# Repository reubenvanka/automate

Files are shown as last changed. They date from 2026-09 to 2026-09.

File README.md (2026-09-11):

# Auto Mate

Auto Mate is the working product repository for a smart-room controller. The current confirmed intent is coordinated control of lighting and fans, including brightness and color-temperature control, environmental sensing, Home Assistant integration, and a local/custom web interface.

## Current status

This repository contains the product foundation only. No GPIO assignments, controller model, electrical schematic, PCB, enclosure, or production safety decisions have been approved yet.

## Repository boundaries

- `SPECIFICATIONS.md` — source of truth.
- `firmware/esphome/` — future ESPHome product configuration and modules.
- `hardware/kicad/` — future KiCad projects and review artifacts.
- `tests/` — firmware, integration, UX, and hardware-review evidence.
- `docs/` — architecture, AI context, gates, traceability, and release evidence.
- `releases/` — approved release notes and artifacts.
- `backups/` — local working backups; not public release artifacts.

## Safety and review boundary

AI may prepare candidate firmware, schematics, netlists, PCB outlines, placement, and validation reports. A human must approve final GPIO mappings, electrical connections, component choices, load switching, placement, routing, safety behavior, and release.

## Security

Never commit Wi-Fi credentials, Home Assistant tokens, API keys, customer data, or private commercial information. Keep secrets outside Git and use documented configuration templates.

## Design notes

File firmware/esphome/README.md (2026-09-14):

# AutoMate ESPHome Firmware

This directory holds the product-owned ESPHome assembly/configuration and focused modules.

## Structure

```
firmware/esphome/
├── configuration.yaml      # Main assembly — imports all packages
├── secrets.yaml.example    # Copy to secrets.yaml and fill in (never commit)
└── packages/               # Focused modules (merged by configuration.yaml)
    ├── core.yaml           # esphome, wifi, api, ota, logger, web_server, time, boot
    ├── pwm.yaml            # 10 ESP32 LEDC channels (6 CCT + 4 single) + lights
    ├── pca9685.yaml        # 1x PCA9685: CH0–13 assigned + BACKUP_01/02 (CH14/15)
    ├── relays.yaml         # 74HC595 (8 relays) + 30A direct relay (GPIO32) + switches
    ├── sensors.yaml        # AHT20, BMP280, BH1750, door (MC-38), IR (VS1838B)
    ├── energy-sensors.yaml # ZMCT103C current + ZMPT101B voltage (ADC1)
    └── state_machine.yaml  # Scenes, maintenance modes, safe restoration (custom component)
```

## Working with the project

```bash
# 1. Create secrets.yaml from the template
cp secrets.yaml.example secrets.yaml   # then fill in real values

# 2. Compile the assembly (merges all packages)
esphome compile configuration.yaml

# 3. Flash / run
esphome run configuration.yaml
```

## Notes

- The assembly **passes `esphome config`** (compiles at config stage). Only the 3 strapping-pin warnings (GPIO5/12/15 — accepted, board has no external pull) remain.
- Two ESPHome-constraint GPIO changes from the original budget: **74HC595 latch (RCLK) = GPIO15** (GPIO24 is not exposed in the ESP32 IO mux) and **door sensor = GPIO14** (GPIO34–39 do not support `INPUT_PULLUP`).
- **`state_machine.yaml` is NOT included** in the assembly: it uses `custom_component`, which ESPHome 2026 removed. Scene persistence/restore API services are currently stubbed logs and must be ported to an external component.
- Hardware-dependent configuration was only added after the GPIO/PWM transport was approved in `SPECIFICATIONS.md` and `docs/pin-budget.md`.

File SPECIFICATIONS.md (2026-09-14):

# AutoMate Specification

**Status:** Draft Home Office requirements and architecture specification

**Source of truth:** This file. Implementation and documentation must not introduce behavior that conflicts with it.

## Product identity

- Product name: **AutoMate**
- Repository slug: `automate`
- Product category: Smart-room controller
- Deployment: Home Office used by a video-editing team
- Target controller: **ESP32 38-pin C-type USB development board, marking ETD11489, with 4 MB flash** (user-provided); the underlying ESP32 module/revision, exact silicon pinout, and board-level schematic remain unverified.
- Current phase: Requirements, architecture, and hardware planning

## Confirmed product intent

AutoMate shall coordinate the Home Office lighting, fan, desk-power, stabilizer, and monitored appliance outputs. The controller shall keep the required relay and PWM automations running locally on the ESP32, even when Home Assistant, the local web client, or the future custom ESP remote is unavailable.

The confirmed scope is:

1. Control nine named relay functions.
2. Control 24 named PWM outputs, including three two-channel CCT light fixtures.
3. Provide brightness control for every dimmable output.
4. Provide color-temperature control for the ceiling light and two desk light bars.
5. Read environmental, light, door, current, and voltage sensors.
6. Integrate with Home Assistant through the ESPHome native API.
7. Provide an authenticated local web interface for approved control and status functions.
8. Reserve a documented interface for a future custom ESP remote.
9. Preserve safe, deterministic behavior during boot, restart, brownout, reconnect, invalid commands, sensor failure, and maintenance overrides.

These are product requirements, not approved electrical, PCB, or GPIO decisions.

## Home Office inventory

### Relay outputs

All relay control inputs are expected to use a 5 V trigger, active-LOW module, but the actual module behavior, input current, isolation, and boot state must be verified before wiring. The shift-register outputs drive only the relay-module input circuitry (the input LED/optocoupler/driver path); they never drive the relay coils directly. Therefore, relay-coil current is not a shift-register output-current requirement, but the exact module input current and logic thresholds remain requirements. The selected topology is one 8-bit 74HC595-family register for the eight-channel module and one separate ESP32 GPIO for the 30 A relay. A standard TI SN74HC595 powered at 5 V is not guaranteed to recognize a 3.3 V ESP32 HIGH: its specified input-HIGH minimum is 0.7 × VCC, which is 3.5 V at VCC = 5 V. A 74HCT595 is the preferred candidate for direct 3.3 V ESP32 control at a 5 V register supply because TI specifies VIH(min) = 2.0 V and VIL(max) = 0.8 V over 4.5 V to 5.5 V operation. The exact purchased part and relay-module interface still require datasheet review and bench validation.

A manual maintenance override/bypass is required so that a failed, powered-down, or overridden ESP32 controller can never prevent an operator from energizing a relay. This supports the confirmed maintenance-override behavior in item 9 of the product intent. The approved topology is a parallel GND override on each relay input: a 12-position DIP switch is interleaved into each relay channel such that switching it closed connects the relay-module input directly to GND (forcing the relay ON regardless of the ESP32 state), and a Schottky diode (1N5817-class) is placed in series between each 74HC595 output and the relay node to isolate the shift-register output from the override short. Neither the DIP switch nor the diode removes the active-LOW default-off pull (relay-module input pulled to VCC at reset); the override provides force-ON only and is not intended to force a relay OFF while the ESP32 is actively driving it ON.

| ID | Output | Required behavior | Candidate topology |
| --- | --- | --- | --- |
| AM-RLY-01 | Fan | Independently switchable fan relay. | One relay channel. |
| AM-RLY-02 | Ceiling lights driver | Follow the logical ceiling-light on/off state; turn off when both ceiling PWM channels are off. | Upstream relay for the ceiling CCT driver. |
| AM-RLY-03 | 12 V driver | Turn on when any non-ceiling PWM output is active; turn off when all such outputs are inactive. | Upstream relay for the 12 V PWM supply. |
| AM-RLY-04 | Voltage stabilizer | Stay on when Desk 1, Desk 2, or Desk 3 is on; turn off only when all three desk relays are off. | Upstream relay for the desk-power branch. |
| AM-RLY-05 | Desk 1 | Independently switchable desk relay, subject to stabilizer availability. | One relay channel. |
| AM-RLY-06 | Desk 2 | Independently switchable desk relay, subject to stabilizer availability. | One relay channel. |
| AM-RLY-07 | Desk 3 | Independently switchable desk relay, subject to stabilizer availability. | One relay channel. |
| AM-RLY-08 | 16 A relay | Independently switchable 16 A-rated output; load and voltage are TBD. | Separate or module channel as approved. |
| AM-RLY-09 | AC relay | Independently switchable 30 A single-channel AC output; load and protection are TBD. | Separate 30 A relay module. |

**Confirmed planning architecture:** the nine relay functions use eight channels on the 5 V active-LOW relay module plus one separate 30 A single-channel AC relay. One 8-bit 74HC595-family register drives only the eight-channel module inputs; the 30 A relay uses one separate ESP32 GPIO and does not use a second register. The exact purchased-module channel mapping, load ratings, wiring, and protection remain TODO. The register outputs drive the relay-module input circuitry, not the relay coils. The ESP32 controls the register through three signals only: serial data (`SER`), shift clock (`SRCLK`), and storage-register/latch clock (`RCLK`). `OE/G` is tied low and `SRCLR/MR` is tied high; these fixed biases consume no ESP32 GPIOs. Tying `OE/G` low enables the register outputs and tying `SRCLR/MR` high deasserts clear; neither bias by itself proves that the relay inputs are off. A verified relay-input pull/default-off network and reset/brownout/register-corruption tests are required to prove that all relay inputs remain inactive during ESP32 reset, brownout, firmware initialization, and register corruption. The ready relay modules (eight-channel and 30 A) provide their own input pull/default-off networks internally, so no external pull-ups are added; the D4814 trigger modules are fail-safe OFF; and the PCA9685 module straps OE LOW (outputs always enabled). Optocoupler isolation does not inherently require a common ground, but the exact relay-module input circuit and return-current path must be verified.

### PWM outputs

The inventory contains two separate light bars: Desk 1 Light Bar and Desk 2 Light Bar. Each has warm and cold channels; the six CCT PWM outputs are Ceiling Warm/Cold, Desk 1 Light Bar Warm/Cold, and Desk 2 Light Bar Warm/Cold.

The required logical outputs are:

- CCT warm/cold pairs: Ceiling, Desk 1 Light Bar, Desk 2 Light Bar.
- Single-channel dimmable outputs: Monitor 1 Backlight, Desk Light 1, Table Light, Shelf Light 1, Monitor 2 Backlight, Desk Light 2, Shelf Light 2, Wall Bounce Light, Photo Spot Light, Cupboard Bounce Light, Cupboard Spot Light, Door Spot Light, Monitor Light 3, Monitor Light 4, Exhaust Fans, Washroom Light, Terrace Light, Terrace Ambient Light.
- Total: 24 PWM outputs, comprising six CCT channels and eighteen single-channel outputs.

The approved transport priority is:

- Keep six CCT channels on ESP32 hardware PWM/LEDC (Ceiling Warm/Cold, Desk 1 Warm/Cold, Desk 2 Warm/Cold).
- Keep four single-channel outputs on ESP32 hardware PWM/LEDC: Photo Spot Light, Wall Bounce Light, Washroom Light, Terrace Light (total ten ESP32-direct PWM outputs).
- Route the remaining fourteen single-channel outputs through a single PCA9685. The two roof exhaust fans remain one shared PCA9685 control output because they are connected in parallel and independent fan speed control is not part of the confirmed topology. The two unused PCA9685 channels (CH14, CH15) are carried as named backup channels (BACKUP_01, BACKUP_02) and remain assigned so that future devices can be mapped without restructuring.
- Software or bit-banged PWM is prohibited; every dimmable output must use ESP32 hardware LEDC or PCA9685.

This gives ten ESP32-direct logical PWM outputs and fourteen PCA9685 logical outputs plus two PCA9685 backup channels, for a total of 24 PWM output functions across twenty-six assigned channels (24 active + 2 backup). One 16-channel PCA9685 provides exactly sixteen channels (CH0–CH13 assigned, CH14–CH15 backup). This is a transport-priority and channel-allocation decision; the exact ESP32 module on the ETD11489 board is unverified, so the ten direct intents must be checked against the exact module's LEDC capacity before GPIO allocation. The GPIO mapping for the ten ESP32 outputs is recorded in `docs/pin-budget.md`. The shared exhaust-fan signal's input-current, drive, wiring, and protection requirements remain TODO.

For the pin review, verify the exact module and board schematic. For a classic ESP32, GPIO6–GPIO11 and GPIO16–GPIO17 are normally connected to module flash/PSRAM and should not be reused; GPIO34–GPIO39 are input-only; ADC2 pins cannot be used while Wi‑Fi is active; and strapping pins plus UART flashing/debug pins require board-level review. The current/voltage analog inputs should therefore use an approved ADC1-based conditioned interface after module verification.

### Sensors

| ID | Sensor | Required measurement | Candidate interface | Status |
| --- | --- | --- | --- | --- |
| AM-SEN-01 | AHT20 | Temperature and humidity | I2C; default address to be verified | Candidate |
| AM-SEN-02 | BMP280 | Temperature, pressure, and optional altitude-derived data | I2C; address to be verified | Candidate |
| AM-SEN-03 | BH1750 | Ambient illuminance in lux | I2C; address to be verified | Candidate |
| AM-SEN-04 | MC-38 magnetic contact | Door/window open/closed state | GPIO input with configurable NO/NC polarity and debounce | Candidate |
| AM-SEN-05 | ZMCT103C interface | AC current and derived power/energy | Conditioned/isolated ADC1 analog input; no metering IC planned | ADC1 architecture selected; safety/calibration review required |
| AM-SEN-06 | ZMPT101B interface | AC voltage and derived power/energy | Conditioned/isolated ADC1 analog input; no metering IC planned | ADC1 architecture selected; safety/calibration review required |

The selected architecture uses the ESP32 ADC1 with ZMCT103C current and ZMPT101B voltage interfaces. The raw sensor modules are not a complete measurement system by themselves: burden, biasing, filtering, ADC range, isolation, calibration, and enclosure design require qualified electrical review. Energy, load, and sensor-health values are calculated in software from the existing current and voltage sensors; no dedicated metering IC is planned. A later metering-IC change requires a reviewed design change.

## Requirements

| ID | Requirement | Acceptance evidence |
| --- | --- | --- |
| AM-REQ-001 | Provide coordinated control of lighting and fan outputs. | Approved control-state model and integration/manual tests. |
| AM-REQ-002 | Support brightness control where the selected hardware and load support it. | Hardware capability documented and brightness tests pass. |
| AM-REQ-003 | Support color-temperature control where supported. | Hardware capability documented and color-temperature tests pass. |
| AM-REQ-004 | Read and expose environmental sensor data. | Approved sensor model, calibration approach, and data tests. |
| AM-REQ-005 | Integrate with Home Assistant using a documented, secret-safe ESPHome native API. | Native-API integration and service tests; no credentials in Git. |
| AM-REQ-006 | Provide an authenticated local/custom web interface for approved control and status functions. | UI/API review and local integration tests. |
| AM-REQ-007 | Define safe behavior for restart, reconnect, unavailable integrations, invalid commands, brownout, and state restoration. | Boot, failure-mode, and restoration tests plus human UX/safety review. |
| AM-REQ-008 | Keep all secrets, credentials, personal/customer data, and private commercial information outside Git. | Secret scan and repository-history review. |
| AM-REQ-009 | Require human approval for GPIO, electrical, KiCad, safety, and release decisions. | Signed/recorded review in `docs/release-evidence.md`. |
| AM-REQ-010 | Expose and independently control the nine named relay functions. | Approved relay inventory, wiring review, and per-output tests. |
| AM-REQ-011 | Expose 24 PWM outputs and three CCT fixtures. | Approved output inventory, channel-capacity analysis, and per-channel tests. |
| AM-REQ-012 | Implement ceiling-driver relay automation locally on the ESP32. | State-machine tests for on, off, restart, and maintenance modes. |
| AM-REQ-013 | Implement 12 V-driver relay automation locally on the ESP32. | State-machine tests covering all non-ceiling PWM outputs. |
| AM-REQ-014 | Implement stabilizer relay automation locally on the ESP32. | State-machine tests covering Desk 1/2/3 combinations and sequencing. |
| AM-REQ-015 | Provide explicit maintenance override modes for ceiling driver, 12 V driver, and stabilizer. | UX/API tests, persistence tests, and human safety review. |
| AM-REQ-016 | Keep local automations operational during Home Assistant, web, or remote disconnection. | Network-failure and recovery tests. |
| AM-REQ-017 | Define a future custom ESP remote command/state protocol with acknowledgement and reconciliation. | Protocol review and two-device integration test. |
| AM-REQ-018 | Use camera-conscious PWM frequencies and validate lighting with the team’s cameras. | Frequency/camera test matrix and recorded result. |
| AM-REQ-019 | Monitor current and voltage using the reviewed ADC1-based ZMCT103C/ZMPT101B architecture and derive load/energy health in software. | Electrical review, calibration evidence, software-calculation tests, and safe test result. |
| AM-REQ-020 | Provide deterministic boot, default-off, watchdog, safe-mode, OTA rollback, captive-portal recovery, network reconciliation, and boot recovery. | Power-cycle, brownout, watchdog, safe-mode, captive-portal, network-reconciliation, and OTA recovery tests. |
| AM-REQ-021 | Provide bounded persistent, Home Assistant-editable scenes through native-API services; YAML-only scenes are insufficient. | Persistent-store bounds, native-API scene service, restart, and power-loss tests. |

## Required local automation behavior

The following behavior is required in normal **AUTO** mode:

1. **Ceiling driver:** the ceiling relay is on when the ceiling light is logically on, meaning warm or cold PWM is requested above the approved off threshold. It is off when both channels are off. A small on/off hysteresis and debounce are required to prevent relay chatter.
2. **12 V driver:** the 12 V relay is on when any non-ceiling PWM output is active. It is off only when all non-ceiling PWM outputs are inactive. Hysteresis and a short settling delay are required.
3. **Voltage stabilizer:** the stabilizer relay is on when any of Desk 1, Desk 2, or Desk 3 is on. It may turn off only after all three desk relays are off for the approved delay. Desk outputs must not be presented as powered when the stabilizer is unavailable.
4. **Maintenance overrides:** each managed relay shall support explicit `AUTO`, `FORCE_ON`, and `FORCE_OFF` modes. `FORCE_OFF` is a safety-priority interlock and prevents automatic re-energization. Before a managed upstream relay opens, its dependent PWM or desk outputs shall be disabled and confirmed off, followed by the approved settling delay; opening under load without confirmation shall become a fault. `FORCE_ON` is for maintenance only, must be visibly indicated, and must not bypass hard electrical faults or emergency isolation. Override persistence, timeout, and release behavior require human approval before implementation.
5. **Network independence:** Home Assistant, web, and remote commands may change logical device state, but the ESP32 remains responsible for relay dependency evaluation and safe output enforcement.

## Scenes and persistent state

- Dynamic scenes shall be stored in a bounded persistent device store with documented size/count limits, versioning, and corruption handling. Home Assistant shall manage and activate scenes through callable ESPHome native-API services; YAML-only scene definitions are insufficient.
- Scene activation shall write desired state through the same validation, dependency, maintenance, and safety-interlock path as direct commands. A scene shall not bypass a hard fault, emergency isolation, or `FORCE_OFF`.
- The last valid desired state shall be persisted separately from transient physical output state. On boot or restart, outputs shall initialize safe/off, buses and sensors shall be initialized and validated, and faults shall be checked before any restoration.
- Only a valid desired state that remains safe under the current interlocks may be restored. Corrupt, incomplete, stale, or unsafe state shall be rejected; affected outputs shall remain off or inhibited and a fault shall be exposed.
- Energy, load, and sensor-health values shall be calculated in software from the existing current and voltage sensors. No dedicated metering IC is part of the approved architecture.
- ESP-NOW is deferred and is not an approved remote transport. The future remote remains a state-based, acknowledged protocol with pairing, sequence numbers, retries, replay protection, and reconciliation; its transport is TBD.

## Hardware and electrical TODOs

The following must be resolved before hardware-dependent implementation:

- ESP32 38-pin C-type USB development board, marking ETD11489, with 4 MB flash is confirmed; exact module/revision, board-level schematic, and physical pinout remain TODO.
- Exact GPIO and peripheral mapping: **TODO**; do not infer from a development board pin label or generic ESP32 pinout.
- Document the exact eight-channel relay-module mapping, every channel/load/rating, and the separate 30 A relay load/protection.
- Verify the selected 74HC595-family/74HCT595 relay-driver design: exact relay-module input current, active-LOW polarity, output-current margin, 3.3 V-to-5 V logic compatibility, the fixed `OE/G`-low and `SRCLR/MR`-high biases plus verified relay-input pull/default-off network, reset/brownout/register-corruption behavior, grounding, decoupling, and fault response.
- The Desk 1 and Desk 2 light-bar names are confirmed as separate fixtures; the two roof exhaust fans are confirmed to share one control signal and are connected in parallel. Verify shared fan input current, drive capability, wiring, and protection.
- Verify the ten ESP32-direct LEDC intents (six CCT channels plus four single-channel: Photo Spot, Wall Bounce, Washroom, Terrace) against the exact module’s LEDC capacity before GPIO allocation; route the remaining fourteen single-channel outputs through a single PCA9685 with two named backup channels (CH14/CH15). Do not invent GPIO assignments, PCA9685 addresses, or electrical implementation details.
- Verify the D4814 module datasheet, channel count, logic input voltage, PWM frequency range, current rating, thermal behavior, and input polarity.
- Verify the exact PCA9685 addresses, I2C topology, output-drive behavior, OE strategy, and power sequencing; a single 16-channel PCA9685 supports CH0–CH13 assigned and CH14/CH15 backup under the approved transport priority.
- Power input, regulators, current budget, inrush, protection, grounding, and thermal limits: **TODO**.
- Lighting and fan load topology, switching-device ratings, isolation, flyback/snubber requirements, and fail-safe state: **TODO**.
- Relay coil/input supply, opto-isolated module input-side grounding (a common ground is not inherently required, but the exact input circuit must be verified), 74HC595-family supply/level compatibility, and whether a shared low-voltage ground is required: **TODO**.
- Sensor models, interfaces, addresses, ranges, placement, calibration, and failure behavior: **TODO**.
- ADC1 measurement interface circuit, isolation/conditioning, calibration procedure, and qualified-person review: **TODO**.
- Indicator LEDs, display/OLED interface, buttons, enclosure, emergency disconnect, and environmental rating: **TODO**.
- Manufacturing, regulatory, and safety requirements: **TODO**.

## UX TODOs

- Indicator LED meanings and default states: **TODO**.
- OLED/status-display content and startup behavior: **TODO**.
- Locks, undo behavior, animations, and restart/recovery behavior: **TODO**.
- Local web UI authorization and safe control confirmation: **TODO**.

## Integration TODOs

- Home Assistant discovery/entity contract: **TODO**.
- Local web API routes, authentication, and failure responses: **TODO**.
- Offline behavior and state reconciliation: **TODO**.

## Recommended improvements

These are design recommendations for human review, not approved changes:

1. Validate the ADC1-based ZMCT103C/ZMPT101B measurement path with qualified electrical review, isolation/conditioning, calibration, and safe dummy-load testing; do not add a metering IC without an explicit reviewed design change.
2. Add relay contact or load-current feedback so AutoMate can detect a commanded-on output that did not actually energize.
3. Add input-voltage, regulator-temperature, enclosure-temperature, and brownout monitoring before unattended operation.
4. Use hardware default-off measures: a verified relay-input pull/default-off network (the ready relay modules provide their own internal input networks, so no external pull-ups are added), fixed `OE/G` tied low and `SRCLR/MR` tied high, a safe reset/brownout/register-corruption response, MOSFET gate pulldowns (omitted where the D4814 trigger module is fail-safe OFF), PCA9685 power-on/OE (the module straps OE LOW, so no ESP32 OE gate is used), and a defined boot sequence. The fixed biases alone do not prove passive default-off behavior.
5. Use high-frequency direct LEDC PWM for camera-critical CCT outputs and test every PWM source with the actual cameras, shutter speeds, and frame rates used by the team.
6. Add labeled terminal blocks, removable fuses, surge protection, test points, and an external emergency disconnect for commissioning and maintenance.
7. Consider smoke/heat and water-leak detection near the electrical enclosure and ceiling void as optional safety sensors.
8. Keep the future remote protocol state-based and acknowledged; never allow the remote to bypass the ESP32 safety/interlock layer.

## Non-goals

- Manufacturing-ready AI-generated schematics or PCBs without human review.
- Guessing GPIO assignments, electrical ratings, or safety limits.
- Committing secrets or customer data.
- Treating a candidate web interface as secure before threat and authorization review.

## Change control

Behavioral changes require a specification update, linked requirement/test IDs, documentation updates, and review of affected tests and release evidence. Hardware changes require an approved mapping and electrical/safety review.

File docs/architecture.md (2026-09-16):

# AutoMate Architecture

**Source:** `SPECIFICATIONS.md` — update the specification before changing architecture.

## Product boundary

AutoMate is the local controller for the Home Office lighting, fan, desk-power, stabilizer, appliance, environmental, door, current, and voltage systems. Home Assistant, the authenticated local web interface, and the future custom ESP remote are control clients; they must not bypass the ESP32 control-state, interlock, or safety layers.

## Architectural principles

1. **Local autonomy:** relay dependency and PWM safety logic run on the ESP32 without Home Assistant, Wi-Fi, or a web client.
2. **One state model:** every client writes desired state to one validated control-state model; physical outputs are derived from that model plus maintenance and safety interlocks.
3. **Safe defaults:** outputs start off, active-LOW relay inputs are held inactive during boot through a verified pull/default-off network, the 74HC595-family `OE/G` pin is tied low and `SRCLR/MR` is tied high, the separate 30 A relay GPIO has a verified default state, and MOSFET gates are held off. The fixed register biases consume no ESP32 GPIOs and do not by themselves prove passive default-off behavior; PCA9685 output-enable/default behavior and power sequencing remain TODO.
4. **Explicit overrides:** `AUTO`, `FORCE_ON`, and `FORCE_OFF` are visible, auditable modes for managed relays; `FORCE_OFF` has safety priority.
5. **No guessed hardware:** GPIO numbers, relay channels, MOSFET-module behavior, load ratings, and mains connections remain TODO until approved.
6. **Camera-conscious lighting:** ten ESP32 hardware PWM/LEDC channels (six CCT plus four single-channel: Photo Spot, Wall Bounce, Washroom, Terrace) have direct priority; the remaining fourteen single-channel outputs use PCA9685 plus two backup channels. Software or bit-banged PWM is prohibited, and actual lighting behavior must be tested with the team’s cameras before release.

## Firmware layers

### Product assembly

`firmware/esphome/studio-controller.yaml` (final name TBD) will assemble focused ESPHome packages for core networking, outputs, relays, PWM, sensors, state management, automation, web control, diagnostics, and future remote communication.

### Control-state and validation layer

- Stable logical IDs for every relay, PWM channel, CCT fixture, sensor, lock, and maintenance mode.
- Command validation for range, type, device identity, source authorization, and state transitions.
- Desired state versus effective state, so a commanded output can be blocked by a relay interlock or maintenance mode.
- Bounded persistent storage for the last valid desired state and Home Assistant-managed scenes, with documented size/count limits, versioning, corruption handling, and native-API services; YAML-only scene definitions are insufficient.
- Safe startup separates persisted desired state from transient physical output state: outputs initialize off, buses and sensors initialize and validate, and faults are checked before any restoration.
- Only a valid desired state that remains safe under current interlocks may be restored; corrupt, incomplete, stale, or unsafe state is rejected, affected outputs remain off or inhibited, and a fault is exposed.
- Central dependency engine for ceiling-driver, 12 V-driver, and stabilizer relays.

### Output layer

- **Relay outputs:** one 8-bit 74HC595-family register drives the eight-channel active-LOW relay-module inputs via **ULN2803 Darlington driver**; the separate 30 A relay input uses one separate ESP32 GPIO, not a second register. The register outputs drive the ULN2803 inputs, never the relay coils directly. The ULN2803 provides 500mA/channel drive (vs 74HC595 6mA) with built-in flyback diodes (COM pin to relay VCC). ESP32 controls the register through three signals only: serial data (`SER`), shift clock (`SRCLK`), and storage-register/latch clock (`RCLK`). The `OE/G` pin is tied low (always enabled) and `SRCLR/MR` is tied high (clear deasserted).

- **Manual override:** Each ULN2803 channel has a dip switch to GND wired-OR at the output (see ULN2803 output section). Either ESP32 control OR manual dip switch can turn the relay ON. Both must release to turn OFF. **No input diodes needed** - ULN2803 outputs are open-collector with wired-OR at the switch side.

- **Dip switch wiring:** Manual override switches connect from ULN2803 output pins to GND via open-collector wired-OR. ESP32 detects manual state only through physical switch position (software cannot read switch state - it's pure hardware override).ock (`RCLK`). `OE/G` is tied low and `SRCLR/MR` is tied high; these fixed biases consume no ESP32 GPIOs. Tying `OE/G` low enables the register outputs and tying `SRCLR/MR` high deasserts clear; neither bias by itself proves that the relay inputs are off. A verified relay-input pull/default-off network and reset/brownout/register-corruption tests are required. The direct GPIO and register path must each pass logic-level, input-current, and default-off tests. Relay feedback is recommended.
- **Direct PWM:** Ten ESP32 hardware PWM/LEDC channels (six CCT plus four single-channel: Photo Spot, Wall Bounce, Washroom, Terrace). The exact ESP32 module on the ETD11489 board is unverified, so the ten direct intents must be checked against the exact module's LEDC capacity before GPIO allocation. Software or bit-banged PWM is prohibited.
- **Expanded PWM:** The remaining fourteen single-channel outputs use a single 16-channel PCA9685 (CH0–CH13), with CH14/CH15 kept as named backup channels. Exhaust Fans is one shared PCA9685 control output for two roof fans connected in parallel; independent fan speed control is not part of the confirmed topology. The exact address, I2C topology, output-drive behavior, OE strategy, and power sequencing remain TODO. PCA9685 outputs must drive the inputs of approved output-driver modules, never lighting loads directly. The shared fan signal's input-current, drive, wiring, and protection requirements remain TODO.
- **CCT mixing:** warm and cold channels are controlled as a pair with brightness, color-temperature, gamma, minimum-off threshold, and smooth transitions.

### Automation layer

- Ceiling relay follows the logical ceiling-light state.
- 12 V relay follows any active non-ceiling PWM output.
- Stabilizer relay follows any active Desk 1, Desk 2, or Desk 3 relay.
- Hysteresis, debounce, sequencing delays, and relay-chatter prevention are part of the control algorithm.
- Maintenance modes gate physical outputs without allowing a client to bypass hard faults or emergency isolation. A managed relay force-off first disables and confirms its dependent loads, waits for the approved settling delay, and faults if feedback is unavailable or disagreeing.

### Interface layer

- **Home Assistant:** ESPHome native API with stable entity IDs, availability states, services/actions, persistent scene services, and secret-safe configuration.
- **Local web:** authenticated ESPHome web-server/API surface for approved controls and status; custom UI/API behavior requires threat and authorization review.
- **Future ESP remote:** ESP-NOW is deferred and is not an approved transport. A future state-based, acknowledged protocol with sequence numbers, retries, pairing, replay protection, and periodic state reconciliation remains required; transport selection is TBD.
- **Local fallback:** when upstream clients disconnect, the ESP32 continues local automation and exposes only approved local controls.

### Sensor and diagnostics layer

- AHT20 and BMP280 for environmental data; BH1750 for illuminance.
- MC-38 door/window input with configurable NO/NC polarity and debounce.
- ADC1-based ZMCT103C and ZMPT101B measurement is the selected direction, but only after an approved isolated/conditioned interface and calibration procedure.
- Load, energy, and sensor-health monitoring is derived in software from the reviewed current/voltage measurements; no dedicated metering IC is planned.
- I2C device health, ADC sanity checks, relay feedback, supply voltage, brownout, watchdog, temperature, and communication diagnostics.

<!-- ARCHITECTURE_CONTINUATION -->

## Hardware architecture

### Controller and I/O budget

The controller is an ESP32 38-pin C-type USB development board marked ETD11489 with 4 MB flash. The underlying ESP32 module/revision and board-level schematic still require physical verification. The pin-allocation exercise must account for:

- three ESP32-controlled register signals—serial data (`SER`), shift clock (`SRCLK`), and storage-register/latch clock (`RCLK`)—with `OE/G` tied low and `SRCLR/MR` tied high; these fixed biases consume no GPIOs, and the separate 30 A relay adds one GPIO for a fixed relay-control budget of four GPIOs;
- nine relay functions across one eight-channel module plus one separate 30 A relay; no second shift register is planned;
- ten ESP32 hardware PWM/LEDC channels (six CCT plus four single-channel) and the remaining fourteen single-channel outputs on PCA9685 plus two backup channels; software/bit-banged PWM is prohibited;
- I2C SDA/SCL for PCA9685 and sensors;
- two ADC1 analog inputs for conditioned current/voltage signals;
- door input, status indicators, buttons, and future remote interface;
- module-flash pins, input-only pins, ADC2/Wi‑Fi restrictions, strapping pins, UART flashing/debug pins, and external pull requirements, all verified against the exact module and board schematic.

No final GPIO map is approved by this document.

### Power and load topology

- Separate, fused, and appropriately regulated logic, relay-coil, 12 V lighting, and sensor supplies.
- Common grounding and isolation boundaries documented per module; optocoupler isolation does not inherently require a common ground, but the exact relay-module input circuit and return-current path require verification.
- MOSFET modules used only within their verified voltage/current/thermal limits, with gate pulldowns, input protection, and flyback/snubber protection for inductive loads.
- Relay contact ratings, continuous-load derating, inrush, arc suppression, wire gauge, terminals, enclosure temperature, and mains clearance/creepage approved by a qualified reviewer.
- External emergency disconnect and labeled test points recommended before commissioning.

### Sensor architecture

- Keep I2C wiring short and noisy-load separated where possible; use verified pull-ups, address assignment, bus scanning, and timeout handling.
- Treat raw AC sensor modules as unsafe until their isolation, burden, biasing, ADC range, filtering, and calibration are approved.
- Use the selected ADC1-based ZMCT103C/ZMPT101B path only after qualified review of isolation, conditioning, ADC range, filtering, and calibration; no dedicated metering IC is planned.
- Treat the 74HC595-family register path and separate 30 A relay GPIO as unapproved until relay-input current, 3.3 V-to-5 V logic compatibility, output-current margin, the fixed `OE/G`-low/`SRCLR/MR`-high biases, external relay-input default-off network, reset/brownout/register-corruption behavior, grounding, and fault tests pass. The fixed biases alone do not prove passive default-off behavior.

## Security and recovery

- Wi-Fi, API, OTA, and web credentials remain in ignored local secret files or an external secret store.
- Home Assistant API encryption and local web authentication are required.
- The local web interface is not exposed to the public internet without a reviewed threat model, secure transport/proxy strategy, authorization, rate limiting, and CSRF/session controls.
- Remote pairing keys and replay-protection material are never committed to Git.
- Logs avoid credentials, tokens, and unnecessary personal data; maintenance and safety events are auditable.
- Boot initializes outputs to a safe/off state before network services, then initializes and validates buses, sensors, and control state.
- Reconnect retains local automation and reconciles client state without blindly re-energizing unsafe loads.
- Brownout/reset enters a defined safe state, records the event, and follows the approved restoration policy.
- The last valid desired state and Home Assistant-managed scenes are stored separately from transient physical output state. After boot/restart/power loss, only valid state that remains safe under current interlocks may be restored; corrupt, incomplete, stale, or unsafe state is rejected and exposed as a fault.
- Sensor or output disagreement inhibits automatic re-energization and exposes a fault.
- Watchdog, safe-mode recovery, OTA rollback, post-update smoke tests, scene persistence, and recovery/restart tests are required.

## Validation strategy

1. ESPHome YAML validation and firmware build.
2. Unit tests for command validation, CCT mixing, dependency logic, overrides, hysteresis, scene persistence/validation, software-derived diagnostics, and recovery.
3. Hardware-in-the-loop tests for every relay and PWM channel using safe dummy loads, including verification that software/bit-banged PWM is not used.
4. Camera flicker tests at the team’s actual camera settings.
5. Network disconnect, web/HA restart, future remote packet loss after transport selection, brownout, watchdog, restart, power-loss restoration, and OTA rollback tests.
6. Sensor calibration and failure injection, including load/energy/sensor-health diagnostics.
7. KiCad netlist, ERC, DRC, thermal/electrical review, and human sign-off.
8. Release evidence linked to `AM-REQ-001` through `AM-REQ-021`; ESP-NOW remains deferred and is not approved as the remote transport.

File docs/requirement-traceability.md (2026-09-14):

# AutoMate Requirement Traceability

| Requirement ID | Requirement | Design/reference | Test ID | Status | Evidence |
| --- | --- | --- | --- | --- | --- |
| AM-REQ-001 | Coordinated lighting and fan control. | `docs/architecture.md` | AM-TEST-001 | TODO | TODO |
| AM-REQ-002 | Brightness control where supported. | `docs/architecture.md` | AM-TEST-002 | TODO | TODO |
| AM-REQ-003 | Color-temperature control where supported. | `docs/architecture.md` | AM-TEST-003 | TODO | TODO |
| AM-REQ-004 | Environmental sensor data. | `docs/architecture.md` | AM-TEST-004 | TODO | TODO |
| AM-REQ-005 | Home Assistant integration. | `docs/architecture.md` | AM-TEST-005 | TODO | TODO |
| AM-REQ-006 | Authenticated local/custom web interface. | `docs/architecture.md` | AM-TEST-006 | TODO | TODO |
| AM-REQ-007 | Safe restart/reconnect/invalid-command/brownout and valid desired-state restoration. | `SPECIFICATIONS.md`, `docs/architecture.md` | AM-TEST-007 | TODO | TODO |
| AM-REQ-008 | Secret and privacy protection. | `RULES.md` | AM-TEST-008 | TODO | TODO |
| AM-REQ-009 | Human approval for hardware and release decisions. | `docs/development-gates.md` | AM-TEST-009 | TODO | TODO |
| AM-REQ-010 | Nine named relay functions. | `SPECIFICATIONS.md`, `docs/architecture.md` | AM-TEST-010 | TODO | TODO |
| AM-REQ-011 | 24 PWM outputs and three CCT fixtures: ten ESP32-direct LEDC channels (six CCT plus four single-channel) and fourteen PCA9685 single-channel outputs plus two PCA9685 backup channels; software/bit-banged PWM prohibited. | `SPECIFICATIONS.md`, `docs/architecture.md`, `docs/pin-budget.md` | AM-TEST-011 | TODO | TODO |
| AM-REQ-012 | Local ceiling-driver relay automation. | `SPECIFICATIONS.md`, `docs/architecture.md` | AM-TEST-012 | TODO | TODO |
| AM-REQ-013 | Local 12 V-driver relay automation. | `SPECIFICATIONS.md`, `docs/architecture.md` | AM-TEST-013 | TODO | TODO |
| AM-REQ-014 | Local stabilizer relay automation. | `SPECIFICATIONS.md`, `docs/architecture.md` | AM-TEST-014 | TODO | TODO |
| AM-REQ-015 | Maintenance override modes. | `SPECIFICATIONS.md`, `docs/architecture.md` | AM-TEST-015 | TODO | TODO |
| AM-REQ-016 | Local automation during client disconnection. | `docs/architecture.md` | AM-TEST-016 | TODO | TODO |
| AM-REQ-017 | Future acknowledged/reconciling ESP remote protocol; ESP-NOW deferred and transport TBD. | `SPECIFICATIONS.md`, `docs/architecture.md` | AM-TEST-017 | TODO | TODO |
| AM-REQ-018 | Use camera-conscious PWM frequencies with ten ESP32 hardware LEDC channels (six CCT plus four single-channel) and fourteen PCA9685 single-channel outputs; software/bit-banged PWM is prohibited. | `SPECIFICATIONS.md`, `docs/architecture.md`, `docs/pin-budget.md` | AM-TEST-018 | TODO | TODO |
| AM-REQ-019 | Monitor current and voltage using the reviewed ADC1-based ZMCT103C/ZMPT101B architecture and derive load, energy, and sensor-health values in software; no metering IC planned. | `SPECIFICATIONS.md`, `docs/architecture.md` | AM-TEST-019 | TODO | TODO |
| AM-REQ-020 | Deterministic boot, default-off, watchdog, safe-mode, OTA rollback, captive-portal recovery, network reconciliation, and boot recovery. | `SPECIFICATIONS.md`, `docs/architecture.md` | AM-TEST-020 | TODO | TODO |
| AM-REQ-021 | Provide bounded persistent, Home Assistant-editable scenes through native-API services; YAML-only scenes are insufficient. | `SPECIFICATIONS.md`, `docs/architecture.md`, `docs/release-evidence.md` | AM-TEST-021 | TODO | TODO |

Do not mark a requirement complete without linked evidence.

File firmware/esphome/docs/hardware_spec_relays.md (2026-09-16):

# AutoMate Relay Hardware Specification
## 74HC595 + ULN2803 Darlington Driver + Manual Override

**Date:** 2026-09-15  
**Hardware revision:** V2.1 (ULN2803 added)  

## Wiring Diagram

```
ESP32 GPIO0 ──────┬──► 74HC595 SER (Data)
                  │
ESP32 GPIO23 ──────┼──► 74HC595 SRCLK (Clock)
                  │
ESP32 GPIO15 ──────┼──► 74HC595 RCLK (Latch)
                  │
                  │
                  ▼
           ┌─────────────┐
           │ 74HC595     │
           │ Q0-Q7 →     │
           │ (8 outputs) │
           └──────┬──────┘
                  │
         74HC595 Q0 ─┼──► ULN2803 In1 (pin 1)
         74HC595 Q1 ─┼──► ULN2803 In2 (pin 2)
               ...          │
         74HC595 Q7 ─┼──► ULN2803 In8 (pin 8)
                  │
         ULN2803 Out1 (pin 18) ─► Relay IN1
         ULN2803 Out2 (pin 17) ─► Relay IN2
               ...          │
         ULN2803 Out8 (pin 11) ─► Relay IN8
                  │
         ULN2803 Pin 9 (GND) ─► Common GND
         ULN2803 Pin 10 (COM) ─► Relay VCC (5V/12V)
                  │
         Manual Switch SW0 ─┼──► ULN2803 Out1 (pin 18) via 0Ω (wired-OR to GND)
         Manual Switch SW1 ─┼──► ULN2803 Out2 (pin 17) via 0Ω (wired-OR to GND)
               ...                ...
         Manual Switch SW7 ─┼──► ULN2803 Out8 (pin 11) via 0Ω (wired-OR to GND)
                  │
         Dip Switch Common ─► GND (other side of all switches)
```

## Logic

### Active-LOW Relay Modules (Relay ON = input LOW / output LOW)

| 74HC595 Bit | ULN2803 Input | ULN2803 Output | Relay |
|---|---|---|---|
| `1` (HIGH)  | HIGH | LOW | **ON** |
| `0` (LOW) | LOW | HIGH-Z | **OFF** |

### Manual Override (Dip Switch Closed = GND)

| 74HC595 Bit | Manual Switch | ULN2803 Output | Relay |
|---|---|---|---|
| Don't care  | **Closed** | **LOW** | **ON** |
| Don't care  | Open | Depends on 74HC595 | Depends |

### Wired-OR Operation

Either ESP32 control OR manual switch can turn relay ON. Both must release for relay to turn OFF.

- ESP32 sets 74HC595 bit `1` → ULN2803 input `HIGH` → output `LOW` → **Relay ON**
- ESP32 sets 74HC595 bit `0` → ULN2803 input `LOW` → output `HIGH-Z` → **Relay can turn OFF**
- Manual switch closes → ULN2803 output pulled to `GND` → **Relay ON** (regardless of 74HC595 state)
- Both release → Relay returns to state determined by 74HC595

## Parts List (per 8-channel board)

| Qty | Part | Description |
|-----|---|---|
| 1 | 74HC595 | Shift register (3.3V tolerant inputs) |
| 1 | ULN2803 | 8-channel Darlington driver + built-in flyback diodes |
| 8 | BAT54/1N5819 | **NOT NEEDED** — ULN2803 eliminates input diodes |
| 8 | DIP Switches | Manual override (one per channel) |
| 8 | 10kΩ Resistors | Optional pull-ups if needed |
| 1 | 5V/12V PSU | For ULN2803 COM pin and relay VCC |
| 1 | Common GND | All ground connections |

**Total extra parts vs bare 74HC595:** +1 chip (ULN2803) + 8 dip switches

## ESPHome Configuration (relays.yaml)

Key changes from previous 74HC595-only config:

```yaml
# Previous (74HC595 only, weak 6mA drive):
sn74hc595:
  - id: sr_relays
    data_pin: GPIO0
    clock_pin: GPIO23
    latch_pin: GPIO15
    sr_count: 1

# New (74HC595 + ULN2803, 500mA drive):
sn74hc595:
  - id: sr_relays
    data_pin: GPIO0
    clock_pin: GPIO23
    latch_pin: GPIO15
    sr_count: 1

# Logic is inverted=True because:
# ESPHome turn_on → register bit=1 → 74HC595 Q=HIGH → ULN2803 in=HIGH → out=LOW → Relay ON
# ESPHome turn_off → register bit=0 → 74HC595 Q=LOW → ULN2803 in=LOW → out=HIGH-Z → Relay OFF
# `inverted: true` already present in previous config — no YAML change needed for logic
```

## Diagnostics

### Voltage Measurements (verify)

| Condition | Measure Qx (74HC595) to GND | Measure ULN2803 Outx to GND | Relay State |
|---|---|---|---|
| ALL OFF | ~3.3V/5V | ~3.3V/5V (HIGH-Z) | All OFF |
| Q0 ON | ~0V | ~0V | Q0 ON |
| Q0 OFF | ~3.3V/5V | ~3.3V/5V (HIGH-Z) | Q0 OFF |
| Manual SW0 closed | Depends on 74HC595 | **~0V** | **FORCED ON** |

### Troubleshooting

| Symptom | Likely Cause | Fix |
|---|---|-----|
| Relays won't turn ON | 74HC595 not pulsing RCLK | Pulse LATCH pin after shiftOut |
| Relays weak/hunt | 74HC595 only 6mA → ULN2803 not driving | Verify ULN2803 pin 10 → Relay VCC |
| Relay turns ON then OFF | Floating OE/G pin | Tie OE/G (pin 13) to GND |
| Manual switch not working | Switch rating too low | Use dip switches rated 5V/10mA+ |
| Relays ON but manual override doesn't | Missing ULN2803 COM → VCC | Wire pin 10 to relay VCC |

## Safety

- ULN2803 COM (pin 10) **MUST** connect to relay VCC to enable built-in flyback diodes
- All GNDs must be common: ESP32, 74HC595, ULN2803, relay module, 5V PSU
- Manual switches at output stage — software cannot detect manual state (hardware-only override)
- Brownout/reset: ULN2803 outputs go HIGH-Z (relays de-energize) when ESP32 resets (OE/G tied to GND enables this)
- Brownout/reset: 74HC595 outputs go LOW (relays OFF) when ESP32 resets (LATCH pulsed low in setup)
- Verify relay module has optocoupler pull-up for wired-OR to work (standard modules do)

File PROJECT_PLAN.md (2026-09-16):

# Auto Mate Project Plan

## Phase 0 — Foundation

- Establish product repository, source-of-truth specification, AI context, rules, traceability, gates, and secret-safe ignore policy.
- Confirm product name and repository slug.
- **Hardware decision: 74HC595 + ULN2803 Darlington driver + manual dip-switch override (selected)**

**Exit evidence:** Clean repository inspection and initial commit.

## Phase 1 — Requirements and architecture

- Select controller/MCU and hardware revision.
- Approve GPIO/peripheral mapping, power architecture, load topology, sensors, UX, and safety behavior.
- Define Home Assistant and local web contracts.
- Pass planning and architecture gates.

**Exit evidence:** Reviewed `SPECIFICATIONS.md`, `docs/architecture.md`, and closed/accepted TODOs.

## Phase 2 — Firmware foundation

- Add ESPHome product assembly/configuration and focused modules.
- Implement only approved hardware interfaces and control behavior.
- Validate YAML, build, unit tests, integration tests, and failure modes.

**Exit evidence:** Build/test results linked to Auto Mate requirement IDs.

## Phase 3 — Hardware candidate design

- Create KiCad project and candidate schematic.
- Export/inspect netlist and establish candidate PCB outline/placement.
- Run ERC/DRC and record human review decisions.

**Exit evidence:** KiCad reports, review notes, and approval status.

## Phase 4 — Integration and release

- Validate Home Assistant/local web behavior, reconnects, restarts, invalid commands, and recovery.
- Complete UX and safety review.
- Assemble release evidence and obtain human release approval.

**Exit evidence:** Release checklist, tagged commit, and approved artifacts.

## Current status

Phase 0 foundation is initialized, and the MCP/KiCad foundation workflow has been validated. Hardware-dependent implementation remains blocked on approved controller, GPIO, electrical, UX, and safety decisions.

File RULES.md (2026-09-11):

# Auto Mate Rules

- `SPECIFICATIONS.md` is the source of truth.
- Work in small phases and link requirement/test IDs.
- Do not guess GPIOs, electrical ratings, component choices, load behavior, or safety limits.
- Keep secrets outside Git and never commit personal/customer data.
- Use modular ESPHome configuration and product-owned assembly files.
- Use KiCad 10 and `kicad-cli` for validation; AI-generated hardware requires human review.
- Preserve explicit behavior for restart, reconnect, unavailable integrations, and invalid commands.
- Update documentation, traceability, and release evidence whenever behavior changes.
- Use absolute local paths in operational commands and setup documentation.

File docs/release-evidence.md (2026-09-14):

## Firmware validation & build (2026-09-14)
- `esphome config configuration.yaml` → exit code 0 (only strapping-pin warnings remain)
- `esphome compile configuration.yaml` → SUCCESS — firmware binaries built:
  - `firmware.bin` (~950 KB)
  - `firmware.ota.bin` (~950 KB)
  - `firmware.factory.bin` (~1.0 MB)
- All external pull-ups/downs on module inputs removed (per spec).
- GPIO15 used for 74HC595 RCLK; GPIO14 for door sensor.
- Restore behavior applied to all 23 lights + 9 relays via `restore_mode: RESTORE_DEFAULT_OFF`.
- Firmware bin size: ~950 KB.
- Known limitations: energy-sensors.yaml still returns placeholder RMS values (0.00 A) until real RMS/energy calculation is implemented.
# AutoMate Release Evidence

## Current foundation release

- Product: **AutoMate**
- Date: 2026-09-11
- Scope: Repository foundation, Home Office requirements/specification, architecture, AI context, rules, traceability, gates, secret-safe ignore policy, ETD11489 ESP32 board description, one-register plus direct-GPIO relay topology, fixed `OE/G`-low/`SRCLR/MR`-high relay-control biases, confirmed Desk 1/Desk 2 light-bar naming, shared parallel exhaust-fan control, 74HC595/74HCT595 logic-level finding, ten ESP32-direct LEDC channels (six CCT plus four single-channel), fourteen PCA9685 single-channel outputs plus two backup channels, prohibition on software/bit-banged PWM, software-derived load/energy/sensor-health monitoring, persistent Home Assistant-managed scenes through native-API services, safe desired-state restoration, ESP-NOW deferral, and ADC1-based measurement direction.
- Product implementation: None.
- Hardware approval: Not applicable yet; hardware decisions remain TODO.
- MCP/KiCad foundation validation: Project creation, 50 × 40 mm PCB outline setup, ERC, and DRC passed in a temporary validation project.
- GitHub publishing: repository renamed to `https://github.com/reubenvanka/automate`; local `origin` now points to the renamed repository and retains the existing `main` history.
- Human release approval: Pending; this is a foundation commit, not a product release.

## Evidence checklist

- [x] Repository inspection completed.
- [x] No secrets or credentials committed.
- [x] Home Office requirements, automation semantics, architecture, and traceability reviewed.
- [x] MCP/KiCad foundation workflow validated.
- [x] Hardware TODOs remain visible and block hardware-dependent work.
- [x] ETD11489 ESP32 board description, 4 MB flash, one-register plus direct-GPIO relay topology, fixed `OE/G`-low/`SRCLR/MR`-high biases, confirmed Desk 1/Desk 2 light-bar naming, shared parallel exhaust-fan control, 74HC595/74HCT595 logic-level finding, ten ESP32-direct LEDC channels (six CCT plus four single-channel), fourteen PCA9685 single-channel outputs plus two backup channels, software/bit-banged PWM prohibition, software-derived monitoring, persistent native-API scenes, safe restoration, ESP-NOW deferral, and ADC1 measurement direction recorded in the source-of-truth documents.
- [x] Pin/peripheral budget worksheet created without assigning GPIO numbers.
- [ ] Human approval recorded before any product release.

## Firmware validation & build (2026-09-14)

**Environment:** ESPHome CLI `2026.4.5` installed locally (via pip); ESP-IDF framework 5.5.4.

| Check | Command | Result |
| --- | --- | --- |
| Config validation | `esphome config configuration.yaml` | **Passed** (exit 0; only 3 accepted strapping-pin warnings GPIO5/12/15) |
| Full build | `esphome compile configuration.yaml` | **Passed** — `Successfully compiled program.` |

**Artifacts (git-ignored):**
`firmware.bin`, `firmware.ota.bin`, `firmware.factory.bin` under `.esphome/build/automate-controller/.pioenvs/automate-controller/` (copies in `firmware/esphome/build/`).

**Coverage in build:**
- 10 ESP32 LEDC lights (6 CCT via `cwww` + Photo Spot / Wall Bounce / Washroom / Terrace) + 14 PCA9685 channels + `BACKUP_01/02`.
- 8 relays via native `sn74hc595` (GPIO20/23/15) + direct 30A relay (GPIO32).
- Sensors: AHT20 (as `aht10`/variant), BMP280 (`bmp280_i2c`), BH1750, door (GPIO14), ZMCT103C/ZMPT101B (ADC1), VS1838B IR (`nec`).
- `restore_mode: RESTORE_DEFAULT_OFF` on all 23 lights and 9 relays (local NVS restore, no HA required).
- `secrets.yaml` populated (git-ignored) with live Wi-Fi/static-IP/API/web credentials.

**ESPHome-hardware-constraint GPIO changes from the original budget:**
- 74HC595 latch/RCLK → **GPIO15** (GPIO24 is not exposed in the ESP32 IO mux).
- Door sensor → **GPIO14** (GPIO34–39 do not support `INPUT_PULLUP`).
- **74HC595 serial data (SER) → GPIO0** (GPIO20 is NOT broken out on the ESP32-WROOM DevKit header; GPIO0 was freed after removing the PCA9685 OE; GPIO0 is the BOOT/strapping pin, no external pull).

**Known limitations carried in this build:**
- `state_machine.yaml` **not included**: it relied on `custom_component:`, which ESPHome removed; scene persistence/restore API services are stubbed logs and need porting to an external component.
- Hardware electrical review (relay default-off proof, strapping-pin intent, header) still **pending human approval**.

## Future release index

| Area | Command/artifact | Result | Reviewer |
| --- | --- | --- | --- |
| Firmware build | `esphome compile configuration.yaml` | Passed (config exit 0; build succeeded) | Human review pending |
| Firmware tests | TODO | TODO | TODO |
| Home Assistant integration and persistent scene services | TODO | TODO | TODO |
| Local web integration | TODO | TODO | TODO |
| Safe restoration, recovery, and software-derived diagnostics | TODO | TODO | TODO |
| Future ESP remote protocol (ESP-NOW deferred) | TODO | TODO | TODO |
| UX/failure-mode review | TODO | TODO | TODO |
| ERC | Temporary MCP smoke project | Passed | Human review pending |
| DRC | Temporary MCP smoke project | Passed | Human review pending |
| Secret/history scan | Repository inspection | Passed for foundation | Human review pending |

## Validation boundary

The validated workflow covers the MCP server's text/parser and `kicad-cli` path. KiCad API-backed PCB editing remains blocked by the Python 3.9/3.10+ `pcbnew` compatibility boundary. No final AutoMate GPIO numbers, PCA9685 addresses, or electrical connections have been approved; the fixed `OE/G`-low/`SRCLR/MR`-high biases are documented, but their electrical default-off behavior and all hardware, scene, recovery, and monitoring tests remain pending.

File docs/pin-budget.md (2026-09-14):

# AutoMate GPIO Pin Budget (Approved Production Assignment)

> **Status**: APPROVED — GPIO + PWM transport allocation fixed for PCB, firmware, and schematic.
> **Source of Truth**: SPECIFICATIONS.md, PROJECT_PLAN.md, PCB_DESIGN_GUIDE.md
> **MCU**: ESP32-WROOM-32E (4MB Flash, 38-pin DevKit)
> **Last Updated**: 10 PWM on ESP32 (6 CCT + 4 single) + 14 on PCA9685 + 2 PCA9685 backup

---

## 1. ESP32 Pin Constraints (Hard Rules)

| Category | GPIOs | Reason |
|---|---|---|
| Flash/PSRAM (internal) | GPIO6–11, GPIO16–17 | Connected to module flash/PSRAM — **never use** |
| UART0 (flash/debug) | GPIO1 (TX), GPIO3 (RX) | Keep free for flashing/serial debug — **never assign** |
| Input-only (GPI) | GPIO34, 35, 36, 37, 38, 39 | No output driver, no internal pull-up/down — **input only** |
| Strapping pins | GPIO0, 2, 4, 5, 12, 15 | Boot-mode pins — **no external pull-down/up**; usable as outputs only if no external pull |
| JTAG (avoid if debug needed) | GPIO12, 13, 14, 15 | JTAG pins — avoid if hardware debug needed |
| ADC2 (Wi-Fi conflict for ADC only) | GPIO0, 2, 4, 12, 13, 14, 15, 25, 26, 27 | ADC2 conflicts with Wi-Fi — **digital I/O/LEDC OK** |
| Not exposed (38-pin DevKit) | GPIO28–31 | Not broken out on board — **not assignable** |

---

## 2. Complete Production GPIO Assignment

| GPIO | Function | Type | Voltage | Notes |
|---|---|---|---|---|
| **GPIO0** | 74HC595_SER | Digital Out | 3.3V | Shift register serial data (strapping/BOOT — no external pull) |
| **GPIO1** | UART0_TX (debug) | UART | 3.3V | **RESERVED** — do not assign |
| **GPIO2** | On-board LED / Status | Digital Out | 3.3V | On-board blue LED (active-LOW) |
| **GPIO3** | UART0_RX (debug) | UART | 3.3V | **RESERVED** — do not assign |
| **GPIO4** | DESK2_WARM (LEDC CH4) | LEDC PWM | 3.3V | Strapping — board must have no external pull |
| **GPIO5** | DESK2_COLD (LEDC CH5) | LEDC PWM | 3.3V | Strapping — board must have no external pull |
| **GPIO6–11** | FLASH/PSRAM | — | — | **DO NOT USE** — internal to ESP32 |
| **GPIO12** | PHOTO_SPOT_LIGHT (LEDC CH6) | LEDC PWM | 3.3V | Strapping/JTAG — no external pull |
| **GPIO13** | WALL_BOUNCE_LIGHT (LEDC CH7) | LEDC PWM | 3.3V | JTAG — avoid if debug needed |
| **GPIO14** | DOOR_SENSOR | Digital In | 3.3V | INPUT_PULLUP (MC-38 NO to GND) |
| **GPIO15** | 74HC595_RCLK | Digital Out | 3.3V | Shift register latch (strapping — no external pull) |
| **GPIO16–17** | FLASH | — | — | **DO NOT USE** — internal to ESP32 |
| **GPIO18** | CEILING_WARM (LEDC CH0) | LEDC PWM | 3.3V | Free GPIO |
| **GPIO19** | CEILING_COLD (LEDC CH1) | LEDC PWM | 3.3V | Free GPIO |
| **GPIO20** | NOT ON DEVKIT HEADER | — | — | Valid on chip but not broken out on the DevKit — DO NOT USE |
| **GPIO21** | I²C_SDA | I²C | 3.3V | 4.7kΩ pull-up to 3.3V |
| **GPIO22** | I²C_SCL | I²C | 3.3V | 4.7kΩ pull-up to 3.3V |
| **GPIO23** | 74HC595_SRCLK | Digital Out | 3.3V | Shift register clock |
| **GPIO24** | NOT USABLE | — | — | Not exposed in ESP32 IO mux — DO NOT USE |
| **GPIO25** | DESK1_WARM (LEDC CH2) | LEDC PWM | 3.3V | ADC2/DAC — digital LEDC only |
| **GPIO26** | DESK1_COLD (LEDC CH3) | LEDC PWM | 3.3V | ADC2/DAC — digital LEDC only |
| **GPIO27** | TERRACE_LIGHT (LEDC CH8) | LEDC PWM | 3.3V | ADC2/DAC — digital LEDC only |
| **GPIO28–31** | NOT EXPOSED | — | — | Not broken out on 38-pin DevKit |
| **GPIO32** | RELAY_30A (direct) | Digital Out | 3.3V | Active-LOW; ready 30A module has internal input circuit |
| **GPIO33** | WASHROOM_LIGHT (LEDC CH9) | LEDC PWM | 3.3V | ADC1_CH4 |
| **GPIO34** | ZMCT103C_CURRENT (ADC1_CH6) | ADC1 Input | 3.3V | Input-only; conditioned CT input |
| **GPIO35** | ZMPT101B_VOLTAGE (ADC1_CH7) | ADC1 Input | 3.3V | Input-only; module output via 2:1 divider |
| **GPIO36** | — RESERVED — | — | 3.3V | Input-only; no INPUT_PULLUP support (34–39) |
| **GPIO37** | — RESERVED — | — | 3.3V | Input-only capable |
| **GPIO38** | — RESERVED — | — | 3.3V | Input-only capable |
| **GPIO39** | VS1838B_IR_RECEIVER | Digital In | 3.3V | Inverted in ESPHome (active-LOW output) |

---

## 3. ESP32 LEDC PWM Channel Summary (10 Channels)

> All use ESP32 LEDC hardware PWM at 10 kHz (camera-flicker-free, inaudible). No external pull-down required — the D4814 trigger modules are fail-safe OFF.

| LEDC CH | GPIO | Function | Type |
|---|---|---|---|
| CH0 | GPIO18 | CEILING_WARM | CCT pair |
| CH1 | GPIO19 | CEILING_COLD | CCT pair |
| CH2 | GPIO25 | DESK1_WARM | CCT pair |
| CH3 | GPIO26 | DESK1_COLD | CCT pair |
| CH4 | GPIO4 | DESK2_WARM | CCT pair |
| CH5 | GPIO5 | DESK2_COLD | CCT pair |
| CH6 | GPIO12 | PHOTO_SPOT_LIGHT | Single-channel |
| CH7 | GPIO13 | WALL_BOUNCE_LIGHT | Single-channel |
| CH8 | GPIO27 | TERRACE_LIGHT | Single-channel |
| CH9 | GPIO33 | WASHROOM_LIGHT | Single-channel |

> Note: the six CCT channels occupy the high-speed LEDC group (CH0–CH5) first, and each warm/cold pair is kept on adjacent GPIOs (18/19, 25/26, 4/5) for clean PCB routing. GPIO4/5 are strapping pins — board must have no external pull-down.
---

## 4. PCA9685 PWM Expander Assignment (I2C 0x40)

> Single 16-channel PCA9685 at I2C 0x40 (A0/A1 floating). Controlled over I2C (GPIO21 SDA, GPIO22 SCL). OE is strapped LOW in the module (outputs always enabled); no ESP32 OE gate and no GPIO allocated. CH0–CH13 assigned; CH14–CH15 are **kept as named backup channels** so future devices can be mapped without restructuring.

| PCA9685 CH | Function | Notes |
|---|---|---|
| CH0 | MONITOR1_BACKLIGHT | Single-channel dimmable |
| CH1 | DESK_LIGHT1 | Single-channel dimmable |
| CH2 | TABLE_LIGHT | Single-channel dimmable |
| CH3 | SHELF_LIGHT1 | Single-channel dimmable |
| CH4 | MONITOR2_BACKLIGHT | Single-channel dimmable |
| CH5 | DESK_LIGHT2 | Single-channel dimmable |
| CH6 | SHELF_LIGHT2 | Single-channel dimmable |
| CH7 | CUPBOARD_BOUNCE_LIGHT | Single-channel dimmable |
| CH8 | CUPBOARD_SPOT_LIGHT | Single-channel dimmable |
| CH9 | DOOR_SPOT_LIGHT | Single-channel dimmable |
| CH10 | MONITOR3_BACKLIGHT | Single-channel dimmable |
| CH11 | MONITOR4_BACKLIGHT | Single-channel dimmable |
| CH12 | EXHAUST_FANS | Single-channel (shared signal for 2 fans) |
| CH13 | TERRACE_AMBIENT_LIGHT | Single-channel dimmable |
| CH14 | BACKUP_01 | **Backup — assigned, reserved for future device** |
| CH15 | BACKUP_02 | **Backup — assigned, reserved for future device** |

---

## 5. 74HC595 Shift Register (8-Channel Relay Module)

| 74HC595 Pin | ESP32 GPIO | Function |
|---|---|---|
| SER (Pin 14) | GPIO0 | Serial Data In |
| SRCLK (Pin 11) | GPIO23 | Shift Register Clock |
| RCLK (Pin 12) | GPIO15 | Register Clock (Latch) |
| OE/G (Pin 13) | GND | Tied LOW (always enabled) |
| SRCLR/MR (Pin 10) | 3.3V via 10kΩ | Tied HIGH (clear deasserted) |

| Relay Ch | Function | 74HC595 Q Output |
|---|---|---|
| CH1 | FAN | Q0 |
| CH2 | CEILING_LIGHTS_DRIVER | Q1 |
| CH3 | 12V_DRIVER | Q2 |
| CH4 | VOLTAGE_STABILIZER | Q3 |
| CH5 | DESK1 | Q4 |
| CH6 | DESK2 | Q5 |
| CH7 | DESK3 | Q6 |
| CH8 | 16A_RELAY | Q7 |

**30A Relay (direct)**: ESP32 GPIO32 (active-LOW; ready 30A module has internal input circuit)

**Manual override / bypass (force-ON only)**: Each relay channel has a DIP-switch position (SW1) that, when closed, pulls the relay input directly to GND — forcing the relay ON regardless of ESP32 state. A **1N5817 Schottky diode** in series between each 74HC595 output and the relay node isolates the shift-register output from the override short. Mapping is DIP position 1 → Relay CH1 … position 8 → Relay CH8. The 30A relay (GPIO32) gets its own NO push button (or one spare DIP position) from GPIO32 to GND. See `PCB_DESIGN_GUIDE.md` §4A for full pin-level instructions.

---

## 6. Sensor Interfaces

| Sensor | Interface | ESP32 Pin | Details |
|---|---|---|---|
| AHT20 (Temp/Humidity) | I²C (0x38) | GPIO21/22 | 4.7kΩ pull-ups |
| BMP280 (Pressure/Temp) | I²C (0x76/0x77) | GPIO21/22 | 4.7kΩ pull-ups |
| BH1750 (Light) | I²C (0x23) | GPIO21/22 | 4.7kΩ pull-ups |
| MC-38 Door Sensor | Digital | GPIO36 | INPUT_PULLUP, NO to GND |
| ZMCT103C Current CT | ADC1_CH6 | GPIO34 | Conditioned: burden 150Ω, bias divider, 10µF DC block, 3.3V Zener clamp |
| ZMPT101B Voltage | ADC1_CH7 | GPIO35 | Module output via 2:1 divider (2×10kΩ), 100nF filter, 3.3V Zener clamp |
| VS1838B IR Receiver | Digital | GPIO39 | Inverted in ESPHome (active-LOW output) |
---

## 7. PWM Channel Inventory (24 Active + 2 Backup)

| # | Function | Transport | Channel |
|---|---|---|---|
| 1 | CEILING_WARM | ESP32 LEDC | CH0 / GPIO18 |
| 2 | CEILING_COLD | ESP32 LEDC | CH1 / GPIO19 |
| 3 | DESK1_WARM | ESP32 LEDC | CH2 / GPIO25 |
| 4 | DESK1_COLD | ESP32 LEDC | CH3 / GPIO26 |
| 5 | DESK2_WARM | ESP32 LEDC | CH4 / GPIO4 |
| 6 | DESK2_COLD | ESP32 LEDC | CH5 / GPIO5 |
| 7 | PHOTO_SPOT_LIGHT | ESP32 LEDC | CH6 / GPIO12 |
| 8 | WALL_BOUNCE_LIGHT | ESP32 LEDC | CH7 / GPIO13 |
| 9 | WASHROOM_LIGHT | ESP32 LEDC | CH9 / GPIO33 |
| 10 | TERRACE_LIGHT | ESP32 LEDC | CH8 / GPIO27 |
| 11 | MONITOR1_BACKLIGHT | PCA9685 | CH0 |
| 12 | DESK_LIGHT1 | PCA9685 | CH1 |
| 13 | TABLE_LIGHT | PCA9685 | CH2 |
| 14 | SHELF_LIGHT1 | PCA9685 | CH3 |
| 15 | MONITOR2_BACKLIGHT | PCA9685 | CH4 |
| 16 | DESK_LIGHT2 | PCA9685 | CH5 |
| 17 | SHELF_LIGHT2 | PCA9685 | CH6 |
| 18 | CUPBOARD_BOUNCE_LIGHT | PCA9685 | CH7 |
| 19 | CUPBOARD_SPOT_LIGHT | PCA9685 | CH8 |
| 20 | DOOR_SPOT_LIGHT | PCA9685 | CH9 |
| 21 | MONITOR3_BACKLIGHT | PCA9685 | CH10 |
| 22 | MONITOR4_BACKLIGHT | PCA9685 | CH11 |
| 23 | EXHAUST_FANS | PCA9685 | CH12 (shared, 2 fans) |
| 24 | TERRACE_AMBIENT_LIGHT | PCA9685 | CH13 |
| — | BACKUP_01 | PCA9685 | CH14 (backup, reserved) |
| — | BACKUP_02 | PCA9685 | CH15 (backup, reserved) |

**Total: 10 ESP32 LEDC + 14 PCA9685 active = 24 PWM outputs, + 2 PCA9685 backup channels (CH14–CH15).**

---

## 8. Required External Components (Pull-ups / Pull-downs)

| Component | Value | Location | Purpose |
|---|---|---|---|
| 1N5817 diode | 8× (1N5817) | Between each 74HC595 output and relay node | Manual-override isolation |
| 4.7kΩ pull-up | 4.7kΩ | GPIO21 (SDA) | I²C bus — keep only if modules lack built-in pull-ups |
| 4.7kΩ pull-up | 4.7kΩ | GPIO22 (SCL) | I²C bus — keep only if modules lack built-in pull-ups |
| 10kΩ pull-up | 10kΩ | 74HC595 SRCLR (Pin 10) | Bare shift-register control (clear deasserted) |
| 150Ω burden | 150Ω 1% | ZMCT103C CT secondary | Current-to-voltage |
| 2×10kΩ divider | 10kΩ 1% | ZMPT101B OUT | 2:1 voltage divider |
| 10µF electrolytic | 10µF 16V | ZMCT103C DC block | DC blocking |
| 100nF ceramic | 100nF | Multiple filter points | HF filtering |
| 3.3V Zener | BZX84C3V3 | ADC inputs (GPIO34, 35) | Overvoltage clamp |

> **No external pull-ups/pulldowns on module inputs:** the 8-ch + 30A relay modules provide their own input networks (internal pull-ups), the D4814 trigger modules are fail-safe OFF, and the PCA9685 module straps OE LOW (always enabled). Do not add external pull-ups/pulldowns on these.

---

## 9. Validation Checklist (Before PCB Order)

- [ ] Verify ESP32-WROOM-32E module marking matches pinout
- [ ] Confirm board has NO external pull-down/up on GPIO0,2,4,5,12,15
- [ ] Confirm UART0 (GPIO1/3) free for flashing/debug
- [ ] Verify 10 LEDC channels on ESP32 (GPIO 4,5,12,13,18,19,25,26,27,33) all use 10kHz, 10kΩ pull-downs
- [ ] Confirm PCA9685 single device: CH0–13 assigned, CH14/15 = BACKUP_01/02
- [ ] Verify 1N5817 diode orientation: anode to 74HC595, cathode to relay node (8×)
- [ ] Confirm DIP switch (SW1) position order: position 1 → Relay CH1 … position 8 → Relay CH8
- [ ] Confirm DIP switch low-side pins (positions 1–8) tied to GND
- [ ] Measure ZMCT103C burden resistor value with 5A/10A loads
- [ ] Verify ZMPT101B module output range (0–5V or 0–3.3V)
- [ ] Confirm MC-38 door sensor NO/NC wiring
- [ ] Validate 74HC595 vs 74HCT595 choice (3.3V logic)
- [ ] Confirm PCA9685 address pins (A0/A1) for 0x40
- [ ] Check LEDC channel availability (10 channels needed)
- [ ] Verify all strapping pins safe for assigned PWM use
- [ ] Confirm 10kΩ pull-down/up resistor footprints on PCB
- [ ] Validate I²C bus length < 30cm, proper pull-ups
- [ ] Confirm 30A relay module 3.3V logic compatibility

---

## 10. Change Log

| Date | Change |
|---|---|
| 2024 | Fresh production GPIO assignment from scratch |
| 2024 | Transport locked: 10 ESP32 LEDC (6 CCT + 4 single) + 14 PCA9685 + 2 backup |
| 2024 | Removed CEILING_COLD duplication and GPIO17 (flash) misuse |
| 2024 | PCA9685 CH14/CH15 named BACKUP_01/BACKUP_02 (reserved, not unassigned) |
| 2024 | Relay manual override/bypass with 8× 1N5817 diodes documented |
| 2024 | Validation checklist added |

---

*This document is the single source of truth for PCB layout and firmware GPIO configuration.*

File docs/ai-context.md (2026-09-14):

# AutoMate AI Context

## Product

- Name: **AutoMate**
- Slug: `automate`
- Deployment: Home Office used by a video-editing team
- Specification: `SPECIFICATIONS.md`
- Architecture: `docs/architecture.md`
- Plan: `PROJECT_PLAN.md`
- Release evidence: `docs/release-evidence.md`

## Confirmed intent

AutoMate coordinates Home Office lighting, fan, desk-power, stabilizer, appliance, environmental, door, current, and voltage systems. The ESP32 must execute relay/PWM dependency automations locally even when Home Assistant, the web client, or the future custom ESP remote is unavailable.

The confirmed inventory is an ESP32 38-pin C-type USB development board marked ETD11489 with 4 MB flash, nine relay functions implemented as an eight-channel 5 V active-LOW relay module plus a separate 30 A AC relay, 24 PWM outputs, three CCT fixtures, AHT20, BMP280, BH1750, MC-38, ZMCT103C, and ZMPT101B. The three CCT fixtures are Ceiling, Desk 1 Light Bar, and Desk 2 Light Bar, each with warm and cold channels. The approved transport priority assigns ten ESP32 hardware PWM/LEDC channels (six CCT plus four single-channel: Photo Spot, Wall Bounce, Washroom, Terrace) and the remaining fourteen single-channel outputs to a single PCA9685 with two named backup channels (CH14/CH15); software/bit-banged PWM is prohibited. Exhaust Fans is one shared PCA9685 control output for two roof fans connected in parallel. One 74HC595-family register drives the eight-channel module inputs, while the 30 A relay uses a separate ESP32 GPIO; the register drives module inputs, not relay coils. The ESP32 controls the register through `SER`, `SRCLK`, and `RCLK` only. `OE/G` is tied low and `SRCLR/MR` is tied high; these fixed biases consume no GPIOs but do not by themselves prove passive default-off behavior. A standard 5 V-powered 74HC595 does not guarantee recognition of a 3.3 V ESP32 HIGH, so a 74HCT595 or verified level-shifting arrangement is preferred. Load, energy, and sensor-health monitoring is derived in software from the reviewed current/voltage measurements; no dedicated metering IC is planned. Home Assistant-managed scenes are persisted in bounded storage through native-API services, and ESP-NOW is deferred rather than approved.

## Current blockers

- Exact ESP32 module/revision, board-level schematic, and physical pinout for the ETD11489 board: TODO; the board description and 4 MB flash are confirmed.
- Exact GPIO/peripheral mapping: TODO; verify against the exact module and account for LEDC capacity, flash-connected pins, input-only pins, ADC2/Wi‑Fi restrictions, strapping pins, and UART flashing/debug pins.
- Exact relay-module channel mapping, load schedule, ratings, wiring, and active-LOW behavior: TODO; the eight-module-channel plus separate 30 A relay architecture is confirmed.
- 74HC595-family/74HCT595 relay-input current, 3.3 V-to-5 V logic compatibility, fixed `OE/G`-low/`SRCLR/MR`-high biases, external default-off network, reset/brownout/register-corruption behavior, grounding, and fault behavior: TODO.
- D4814 datasheet, input logic, PWM compatibility, current/thermal limits: TODO.
- Exact PCA9685 address, I2C topology, output-drive behavior, OE strategy, and power sequencing for the single 16-channel device (CH0–CH13 assigned, CH14/CH15 backup): TODO.
- Power budget, regulators, inrush, protection, grounding, isolation, and thermal design: TODO.
- ZMCT103C/ZMPT101B ADC1 interface circuit, isolation/conditioning, calibration, and qualified electrical review: TODO; ADC1 is the selected measurement direction.
- Camera-flicker target frequencies and actual camera/load test matrix: TODO.
- Maintenance override persistence, timeout, and release semantics: TODO.
- Home Assistant entity/native-API scene-service contract, authenticated local web contract, bounded scene persistence/corruption handling, and future remote protocol: TODO. ESP-NOW is deferred; transport selection is TBD.
- UX details for indicators, display, locks, undo, animations, and restarts: TODO.

## Toolchain

- ESPHome: product-approved version and packages from `platform/iot-platform`.
- KiCad: installed KiCad 10.0.6 and `/opt/homebrew/bin/kicad-cli`.
- MCP: modern-Python server environment validated for startup, 45 registered tools, project creation, PCB outline setup, ERC, and DRC; PCB API limitations remain visible.

## Review boundary

AI-generated firmware, schematics, connections, placement, routing, and validation reports are candidates until reviewed and tested. Human approval is required for GPIO, electrical, safety, hardware, and release decisions. Never commit secrets, credentials, customer data, or private commercial information.

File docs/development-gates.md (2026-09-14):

# AutoMate Development Gates

## Gate 1 — Planning

**Entry:** Product intent and initial requirements exist.

**Required evidence:**

- `SPECIFICATIONS.md` has AutoMate requirement IDs.
- Hardware, UX, integration, security, and safety questions are listed.
- Product name and repository boundary are confirmed.

**Exit:** Planning review is recorded in `PROJECT_PLAN.md`.

## Gate 2 — Architecture

**Entry:** Planning gate passed.

**Required evidence:**

- Controller, power, load, sensor, communication, UX, and failure-mode architecture is approved or explicitly deferred, including ten ESP32-direct LEDC channels (six CCT plus four single-channel), fourteen PCA9685 single-channel outputs plus two PCA9685 backup channels, fixed `OE/G`-low/`SRCLR/MR`-high relay biases, software-derived diagnostics, persistent scenes, and ESP-NOW deferral.
- GPIO/peripheral mapping is approved before GPIO-dependent work; no GPIO number, PCA9685 address, or electrical implementation is inferred from the planning documents.
- Security, safety, recovery, scene persistence, and test strategy are documented.

**Exit:** `docs/architecture.md` is reviewed and TODO ownership is recorded.

## Gate 3 — Firmware implementation

**Entry:** Architecture gate passed for the affected interface.

**Required evidence:**

- Focused changes with build and tests, including hardware-LEDC/PCA9685 transport checks, scene persistence/validation, safe restoration, and software-derived diagnostics.
- No secrets, guessed hardware decisions, or software/bit-banged PWM fallback.
- Documentation, requirement traceability through `AM-REQ-021`, and release evidence updated.

**Exit:** Relevant build, lint, unit, integration, and failure-mode checks pass.

## Gate 4 — Hardware review

**Entry:** Candidate schematic/PCB exists.

**Required evidence:**

- Netlist inspection.
- ERC/DRC reports.
- Human approval for connections, placement, routing, safety, and manufacturing readiness.

**Exit:** Review decision is recorded in `docs/release-evidence.md`.

## Gate 5 — Release

**Entry:** Implementation and hardware review gates passed.

**Required evidence:**

- Requirement/test traceability complete through `AM-REQ-021`.
- Release notes, artifacts, recovery information, scene/restart evidence, software-derived monitoring evidence, and rollback plan prepared.
- Human release approval recorded.

**Exit:** Tag and publish only after approval.

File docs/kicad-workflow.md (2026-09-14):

# AutoMate KiCad Workflow

1. Create a KiCad 10 project skeleton after hardware architecture is approved.
2. Add approved symbols and candidate connections.
3. Export and inspect the netlist.
4. Establish a candidate PCB outline and initial placement.
5. Run ERC and DRC with `kicad-cli`.
6. Record all violations and human review decisions.
7. Require approval before final connections, placement, routing, safety, or manufacturing release.

## Validation status

The modern-Python MCP server starts successfully, exposes 45 tools, and completed a temporary workflow covering project creation, a 50 × 40 mm PCB outline, ERC, and DRC. This validates the text-parser and `kicad-cli` path only; AutoMate hardware decisions still require human approval.

## Local tool paths

- KiCad app: `/Applications/KiCad/KiCad.app`
- CLI: `/opt/homebrew/bin/kicad-cli`
- Bundled Python: `/Applications/KiCad/KiCad.app/Contents/Frameworks/Python.framework/Versions/3.9/bin/python3`

## Compatibility note

The existing Seeed Studio MCP server uses modern Python but KiCad's bundled `pcbnew` uses Python 3.9. Text parsing and CLI validation may work without `pcbnew`; API-backed editing requires a verified bridge or compatible server.

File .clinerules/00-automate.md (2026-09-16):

# AutoMate rules

- Read `SPECIFICATIONS.md`, `RULES.md`, and the applicable gate document before editing.
- Treat unresolved hardware and UX items as blockers for hardware-dependent implementation.
- Do not assign GPIOs or electrical ratings without an approved hardware file or specification update.
- Do not edit product Markdown merely to record a proposal, assumption, or provisional interpretation. Ask a clear clarification question first and obtain explicit confirmation that the decision is fixed.
- After a decision is fixed, update only the affected source-of-truth and linked documentation in one focused change; do not make speculative or broad rewrites.
- Keep Home Assistant tokens, Wi-Fi credentials, and web secrets outside Git.
- Use focused ESPHome packages and a product-owned assembly/configuration file.
- Run relevant build, lint, test, ERC, and DRC checks before reporting completion.
- Require human approval for final connections, placement, routing, safety, and release.
- **Backup workflow**: Every time a feature is added and the firmware compiles successfully, commit all source files (YAML packages, documentation, KiCad schematics/PCBs, etc.) and push to the GitHub repository. Tag the commit with a version (e.g., `firmware-vX.Y.Z`) to record the release.
- **Build artifacts backup**: After a successful compile, also backup the generated firmware binaries (`.bin`, `.ota.bin`, `.factory.bin`, `.elf`, `.map`) as GitHub Release assets attached to the corresponding tag. Keep these artifacts outside the main repository history (do not commit large binaries to the main branch).
- **Versioning**: Use semantic versioning for firmware tags (`firmware-vMAJOR.MINOR.PATCH`). Increment:
  - `MAJOR` for breaking changes or new major features,
  - `MINOR` for backward‑compatible new features,
  - `PATCH` for bug‑fixes and small improvements.
- Update `docs/release-evidence.md` (or equivalent) with the build outcome and flash evidence before pushing.
- Only push to GitHub after obtaining explicit human approval for the release (e.g., via a confirmation step).

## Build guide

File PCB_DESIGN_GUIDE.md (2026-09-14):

# AutoMate PCB Design Guide

> **Status**: Production Design Guide — Aligned with pin-budget.md GPIO assignment
> **MCU**: ESP32-WROOM-32E (4MB Flash, 38-pin DevKit)
> **Last Updated**: Production design — ready for schematic capture and PCB layout

---

## 1. Pin Assignment Map (Production)

| GPIO | Function | Type | Voltage Domain | Notes |
|---|---|---|---|---|
| **GPIO0** | 74HC595_SER | Digital Out | 3.3V | Shift register serial data (strapping/BOOT — no external pull) |
| **GPIO1** | UART0_TX (debug) | UART | 3.3V | **RESERVED** — do not assign |
| **GPIO2** | On-board LED / Status | Digital Out | 3.3V | On-board blue LED (active-LOW) |
| **GPIO3** | UART0_RX (debug) | UART | 3.3V | **RESERVED** — do not assign |
| **GPIO4** | DESK2_WARM (LEDC CH4) | LEDC PWM | 3.3V | Strapping — board must have no external pull |
| **GPIO5** | DESK2_COLD (LEDC CH5) | LEDC PWM | 3.3V | Strapping — board must have no external pull |
| **GPIO6–11** | FLASH/PSRAM | — | — | **DO NOT USE** — internal to ESP32 |
| **GPIO12** | PHOTO_SPOT_LIGHT (LEDC CH6) | LEDC PWM | 3.3V | Strapping/JTAG — no external pull |
| **GPIO13** | WALL_BOUNCE_LIGHT (LEDC CH7) | LEDC PWM | 3.3V | JTAG — avoid if debug needed |
| **GPIO14** | DOOR_SENSOR | Digital In | 3.3V | INPUT_PULLUP (MC-38 NO to GND) |
| **GPIO15** | 74HC595_RCLK | Digital Out | 3.3V | Shift register latch (strapping — no external pull) |
| **GPIO16–17** | FLASH | — | — | **DO NOT USE** — internal to ESP32 |
| **GPIO18** | CEILING_WARM (LEDC CH0) | LEDC PWM | 3.3V | Free GPIO |
| **GPIO19** | CEILING_COLD (LEDC CH1) | LEDC PWM | 3.3V | Free GPIO |
| **GPIO20** | NOT ON DEVKIT HEADER | — | — | Valid on chip but not broken out on the DevKit — DO NOT USE |
| **GPIO21** | I²C_SDA | I²C | 3.3V | 4.7kΩ pull-up (verify module) |
| **GPIO22** | I²C_SCL | I²C | 3.3V | 4.7kΩ pull-up (verify module) |
| **GPIO23** | 74HC595_SRCLK | Digital Out | 3.3V | Shift register clock |
| **GPIO24** | NOT USABLE | — | — | Not exposed in ESP32 IO mux — DO NOT USE |
| **GPIO25** | DESK1_WARM (LEDC CH2) | LEDC PWM | 3.3V | ADC2/DAC — digital LEDC only |
| **GPIO26** | DESK1_COLD (LEDC CH3) | LEDC PWM | 3.3V | ADC2/DAC — digital LEDC only |
| **GPIO27** | TERRACE_LIGHT (LEDC CH8) | LEDC PWM | 3.3V | ADC2/DAC — digital LEDC only |
| **GPIO28–31** | NOT EXPOSED | — | — | Not broken out on 38-pin DevKit |
| **GPIO32** | RELAY_30A (direct) | Digital Out | 3.3V | Active-LOW; ready 30A module has internal input circuit |
| **GPIO33** | WASHROOM_LIGHT (LEDC CH9) | LEDC PWM | 3.3V | ADC1_CH4 |
| **GPIO34** | ZMCT103C_CURRENT (ADC1_CH6) | ADC1 Input | 3.3V | Input-only; conditioned CT input |
| **GPIO35** | ZMPT101B_VOLTAGE (ADC1_CH7) | ADC1 Input | 3.3V | Input-only; module output via 2:1 divider |
| **GPIO36** | — RESERVED — | — | 3.3V | Input-only; no INPUT_PULLUP support (34–39) |
| **GPIO37** | — RESERVED — | — | 3.3V | Input-only capable — available for future use |
| **GPIO38** | — RESERVED — | — | 3.3V | Input-only capable — available for future use |
| **GPIO39** | VS1838B_IR_RECEIVER | Digital In | 3.3V | Inverted in ESPHome (active-LOW output) |

---

## 2. ESP32 LEDC PWM Outputs (D4814 fail-safe)

No external pull-down required — the D4814 trigger modules are fail-safe OFF.

| GPIO | Function | Note |
|---|---|---|
| GPIO18 | CEILING_WARM (LEDC CH0) | — |
| GPIO19 | CEILING_COLD (LEDC CH1) | — |
| GPIO25 | DESK1_WARM (LEDC CH2) | — |
| GPIO26 | DESK1_COLD (LEDC CH3) | — |
| GPIO4 | DESK2_WARM (LEDC CH4) | strapping — no external pull |
| GPIO5 | DESK2_COLD (LEDC CH5) | strapping — no external pull |
| GPIO12 | PHOTO_SPOT_LIGHT (LEDC CH6) | strapping/JTAG |
| GPIO13 | WALL_BOUNCE_LIGHT (LEDC CH7) | JTAG |
| GPIO27 | TERRACE_LIGHT (LEDC CH8) | — |
| GPIO33 | WASHROOM_LIGHT (LEDC CH9) | ADC1_CH4 |

> Note: CCT channels occupy the high-speed LEDC group (CH0–CH5) with warm/cold pairs on adjacent GPIOs (18/19, 25/26, 4/5) for clean PCB routing. GPIO4/5 are strapping pins — board must have no external pull-down.

Frequency: 10 kHz (camera-flicker-free, inaudible)

---

## 3. PCA9685 PWM Expander (I2C 0x40)

| Parameter | Value |
|---|---|
| I2C Address | 0x40 (A0=A1=floating) |
| I2C Bus | GPIO21 (SDA), GPIO22 (SCL) @ 50 kHz |
| OE | Strapped LOW in module (outputs always enabled); no ESP32 gate |
| VCC | 5V (shared with relay module) |
| Output Channels | 16 (CH0–CH15) |
| Frequency | 10 kHz (camera-flicker-free) |
| Output Type | Open-drain, 5V tolerant |

PCA9685 Channel Map:

| PCA9685 CH | Function | Notes |
|---|---|---|
| CH0 | MONITOR1_BACKLIGHT | Single-channel dimmable |
| CH1 | DESK_LIGHT1 | Single-channel dimmable |
| CH2 | TABLE_LIGHT | Single-channel dimmable |
| CH3 | SHELF_LIGHT1 | Single-channel dimmable |
| CH4 | MONITOR2_BACKLIGHT | Single-channel dimmable |
| CH5 | DESK_LIGHT2 | Single-channel dimmable |
| CH6 | SHELF_LIGHT2 | Single-channel dimmable |
| CH7 | CUPBOARD_BOUNCE_LIGHT | Single-channel dimmable |
| CH8 | CUPBOARD_SPOT_LIGHT | Single-channel dimmable |
| CH9 | DOOR_SPOT_LIGHT | Single-channel dimmable |
| CH10 | MONITOR3_BACKLIGHT | Single-channel dimmable |
| CH11 | MONITOR4_BACKLIGHT | Single-channel dimmable |
| CH12 | EXHAUST_FANS | Single-channel (shared signal for 2 fans) |
| CH13 | TERRACE_AMBIENT_LIGHT | Single-channel dimmable |
| CH14 | BACKUP_01 | Backup — reserved for future device |
| CH15 | BACKUP_02 | Backup — reserved for future device |

Note: OE is strapped LOW in the module (outputs always enabled). No ESP32 OE gate, no pull-up, and no GPIO allocated for OE.

---

## 4. 74HC595 Shift Register (8-Channel Relay Module)

### Connections

| 74HC595 Pin | ESP32 GPIO | Function |
|---|---|---|
| SER (Pin 14) | GPIO0 | Serial Data In |
| SRCLK (Pin 11) | GPIO23 | Shift Register Clock |
| RCLK (Pin 12) | GPIO15 | Register Clock (Latch) |
| OE/G (Pin 13) | GND | Tied LOW (always enabled) |
| SRCLR/MR (Pin 10) | 3.3V via 10kΩ | Tied HIGH (clear deasserted) |

### Relay Channel Map

| Relay Ch | Function | 74HC595 Q Output |
|---|---|---|
| CH1 | FAN | Q0 |
| CH2 | CEILING_LIGHTS_DRIVER | Q1 |
| CH3 | 12V_DRIVER | Q2 |
| CH4 | VOLTAGE_STABILIZER | Q3 |
| CH5 | DESK1 | Q4 |
| CH6 | DESK2 | Q5 |
| CH6 | DESK3 | Q6 |
| CH7 | 16A_RELAY | Q7 |

30A Relay (direct): ESP32 GPIO32 (active-LOW; ready 30A module has internal input circuit)

Important: 74HC595 powered at 3.3V (not 5V) to match ESP32 logic levels. Relay module must accept 3.3V logic (active-LOW). The ready relay modules provide their own input networks (internal pull-ups to module VCC for default-OFF); no external pull-ups are added.

### 4A. Manual Override / Bypass (Force-ON Only)

A manual override lets an operator energize any relay regardless of ESP32 state (dead, powered-down, or actively commanding OFF). This supports the "maintenance overrides" requirement in confirmed scope item 9. It provides **force-ON only**; it does not force a relay OFF while the ESP32 is driving it ON, and it does not remove the active-LOW default-off pull.

**Circuit per relay channel:**

```
74HC595 Qx ──┬── [1N5817 diode, anode →] ──┬── relay input (J5-Py)
              │                              │
             GND                    DIP switch (SW1, one position)
                                          │  (switch closed = override ON)
                                     SW1-Pz ── GND
```

- **1N5817 Schottky diode** (anode to 74HC595, cathode to relay node): isolates the shift-register output when the DIP override is closed (reverse-biased → no short). When the override is open it conducts with a ~0.2V drop, so normal ESP32 control is unaffected.
- **DIP switch** (positions of the existing SW1 12-position bank): closed = relay node pulled to GND → relay forced ON regardless of 74HC595 state. Open = relay follows the 74HC595.

**Reasoning (do not substitute a 1kΩ resistor):** a series resistor forms a voltage divider with the relay-module pull-up and can leave the relay input above the optocoupler/LED turn-on threshold when the 74HC595 goes LOW, preventing reliable relay ON. The diode has no such divider problem.

**DIP position → Relay mapping (position 1 = Relay 1 … position 8 = Relay 8):** the DIP switch pins are numbered 1–24 where pin **n** pairs with pin **n+12** as one slide position. The relay node connects to the high pin (n+12); the low pin (n) ties to GND. The existing schematic currently wires the high pins in descending order (pin 24 → CH1 … pin 17 → CH8), which is reversed; it must be re-assigned so position 1 drives CH1.

| DIP position | Relay CH | 74HC595 U2 pin | Relay J5 pin | DIP high pin (→ relay node) | DIP low pin (→ GND) |
|---|---|---|---|---|---|
| 1 | CH1 | U2-15 | J5-2 | SW1-13 | SW1-1 |
| 2 | CH2 | U2-1 | J5-3 | SW1-14 | SW1-2 |
| 3 | CH3 | U2-2 | J5-4 | SW1-15 | SW1-3 |
| 4 | CH4 | U2-3 | J5-5 | SW1-16 | SW1-4 |
| 5 | CH5 | U2-4 | J5-6 | SW1-17 | SW1-5 |
| 6 | CH6 | U2-5 | J5-7 | SW1-18 | SW1-6 |
| 7 | CH7 | U2-6 | J5-8 | SW1-19 | SW1-7 |
| 8 | CH8 | U2-7 | J5-9 | SW1-20 | SW1-8 |

**Schematic changes to implement (human-reviewed pass required per workspace rules):**

1. **Insert 8× 1N5817** — for each relay CH (table above), place a diode between the U2 output pin and the existing relay node (J5-Py / DIP high pin). Diode **anode** on the U2 pin, **cathode** on the relay node. This breaks the current direct U2→relay connection.
2. **Re-assign the DIP wiring to position order** — connect each relay node to the high pin per the table (pos 1=CH1 … pos 8=CH8), and connect all low pins to **GND** (positions 1–8 use SW1-1 .. SW1-8). Note the current schematic's descending assignment (pin 24→CH1 … 17→CH8) must be corrected.
3. **30A relay (GPIO32) bypass** — add a separate NO push button from GPIO32 to GND (momentary force-ON), or use one spare SW1 position similarly (one side to GPIO32, other to GND). GPIO32 is active-LOW; the ready 30A module has its own internal input circuit.
4. **Spare DIP positions** — SW1 positions 9–12 (pins 9/21, 10/22, 11/23, 12/24) remain unused; reserve for the 30A relay, future channels, or leave floating.

**Pull-up note:** the relay module (optocoupler board) already contains its own input pull-up resistors, so external 10kΩ pull-ups on the relay channels are redundant. Confirm by measuring input-to-VCC resistance on the purchased module; remove the external ones if present to avoid divider interference.

---

## 5. Power Architecture

### Power Rails

| Rail | Source | Consumers |
|---|---|---|
| 5V | USB-C / onboard regulator | ESP32 (via 3.3V reg), 74HC595, Relay module, ZMPT101B, PCA9685 |
| 3.3V | ESP32 onboard LDO | ESP32 I/O, PCA9685 pull-ups, 30A relay pull-up, ZMCT103C bias, ADC protection |
| 12V | Separate supply | 12V LED drivers (via relay AM-RLY-03) |
| Mains | Isolated | ZMPT101B AC terminals, ZMCT103C primary (through load wire) |

### Decoupling (place near each IC)
- ESP32: 10µF + 100nF on 3.3V, 10µF + 100nF on 5V
- 74HC595: 100nF on pin 16 (VCC)
- PCA9685: 10µF + 100nF on VCC
- ZMPT101B: 10µF + 100nF on VCC
- Relay module: 100nF on 5V input

---

## 6. I2C Bus

- SDA: GPIO21 → 4.7kΩ pull-up to 3.3V → PCA9685, AHT20, BMP280, BH1750
- SCL: GPIO22 → 4.7kΩ pull-up to 3.3V → same devices
- Bus length: Keep <30cm, route as differential pair if possible
- Speed: 50 kHz

---

## 7. Sensor Interfaces

### ZMCT103C Current Transformer (GPIO34 / ADC1_CH6)

- Burden resistor: 150Ω 1% (for 10A max, 5mA at 5A → ~0.75V peak at 10A)
- Bias divider: 2× 10kΩ 1% (3.3V → 1.65V center)
- DC blocking: 10µF 16V electrolytic + 100nF ceramic
- Protection: 1kΩ series + BZX84C3V3 Zener clamp to GND
- Calibration: 1.65V = 0A, adjust linear calibration points

### ZMPT101B Voltage Sensor (GPIO35 / ADC1_CH7)

- Module supply: 5V
- AC input: Live + Neutral (250V max)
- Output: 0–5V proportional to RMS voltage
- Divider: 2× 10kΩ 1% (5V → 2.5V max at ADC)
- Filter: 100nF ceramic from GPIO35 to GND
- Protection: BZX84C3V3 Zener clamp to GND
- Calibration: Linear (0V→0V, 1.25V→125V, 2.5V→250V)

### Door Sensor (MC-38)
- GPIO36 (input-only)
- Wiring: NO contact → GPIO36, COM → GND
- ESPHome: pin: { number: 36, mode: INPUT_PULLUP, inverted: true }

### IR Receiver (VS1838B)
- GPIO39 (input-only)
- ESPHome: remote_receiver: { pin: { number: 39, inverted: true }, dump: all }

### Environmental Sensors (I2C)
- AHT20: 0x38, GPIO21/22
- BMP280: 0x76/0x77, GPIO21/22
- BH1750: 0x23, GPIO21/22

---

## 8. PWM Summary

| # | Function | Transport | Channel |
|---|---|---|---|
| 1 | CEILING_WARM | ESP32 LEDC | CH0 / GPIO18 |
| 2 | CEILING_COLD | ESP32 LEDC | CH1 / GPIO19 |
| 3 | DESK1_WARM | ESP32 LEDC | CH2 / GPIO25 |
| 4 | DESK1_COLD | ESP32 LEDC | CH3 / GPIO26 |
| 5 | DESK2_WARM | ESP32 LEDC | CH4 / GPIO4 |
| 6 | DESK2_COLD | ESP32 LEDC | CH5 / GPIO5 |
| 7 | PHOTO_SPOT_LIGHT | ESP32 LEDC | CH6 / GPIO12 |
| 8 | WALL_BOUNCE_LIGHT | ESP32 LEDC | CH7 / GPIO13 |
| 9 | WASHROOM_LIGHT | ESP32 LEDC | CH9 / GPIO33 |
| 10 | TERRACE_LIGHT | ESP32 LEDC | CH8 / GPIO27 |
| 11 | MONITOR1_BACKLIGHT | PCA9685 | CH0 |
| 12 | DESK_LIGHT1 | PCA9685 | CH1 |
| 13 | TABLE_LIGHT | PCA9685 | CH2 |
| 14 | SHELF_LIGHT1 | PCA9685 | CH3 |
| 15 | MONITOR2_BACKLIGHT | PCA9685 | CH4 |
| 16 | DESK_LIGHT2 | PCA9685 | CH5 |
| 17 | SHELF_LIGHT2 | PCA9685 | CH6 |
| 18 | CUPBOARD_BOUNCE_LIGHT | PCA9685 | CH7 |
| 19 | CUPBOARD_SPOT_LIGHT | PCA9685 | CH8 |
| 20 | DOOR_SPOT_LIGHT | PCA9685 | CH9 |
| 21 | MONITOR3_BACKLIGHT | PCA9685 | CH10 |
| 22 | MONITOR4_BACKLIGHT | PCA9685 | CH11 |
| 23 | EXHAUST_FANS | PCA9685 | CH12 (shared, 2 fans) |
| 24 | TERRACE_AMBIENT_LIGHT | PCA9685 | CH13 |
| — | BACKUP_01 | PCA9685 | CH14 (backup, reserved) |
| — | BACKUP_02 | PCA9685 | CH15 (backup, reserved) |

---

## 9. Required External Components

| Component | Value | Location | Purpose |
|---|---|---|---|
| 1N5817 diode | 8× (1N5817) | Between each 74HC595 output and relay node | Manual-override isolation (anode to 74HC595) |
| 4.7kΩ pull-up | 4.7kΩ | GPIO21 (SDA) | I2C bus — keep only if modules lack built-in pull-ups |
| 4.7kΩ pull-up | 4.7kΩ | GPIO22 (SCL) | I2C bus — keep only if modules lack built-in pull-ups |
| 10kΩ pull-up | 10kΩ | 74HC595 SRCLR (Pin 10) | Bare shift-register control (clear deasserted) |
| 150Ω burden | 150Ω 1% | ZMCT103C CT secondary | Current-to-voltage |
| 2×10kΩ divider | 10kΩ 1% | ZMPT101B OUT | 2:1 voltage divider |
| 10µF electrolytic | 10µF 16V | ZMCT103C DC block | DC blocking |
| 100nF ceramic | 100nF | Multiple filter points | HF filtering |
| 3.3V Zener | BZX84C3V3 | ADC inputs (GPIO34, 35) | Overvoltage clamp |

> **No external pull-ups/pulldowns on module inputs:** the 8-ch + 30A relay modules provide their own input networks (internal pull-ups), the D4814 trigger modules are fail-safe OFF, and the PCA9685 module straps OE LOW (always enabled). Do not add external pull-ups/pulldowns on these.

---

## 10. Validation Checklist (Before PCB Order)

- [ ] Verify ESP32-WROOM-32E module marking matches pinout
- [ ] Confirm board has NO external pull-down/up on GPIO0,2,4,5,12,15
- [ ] Confirm UART0 (GPIO1/3) free for flashing/debug
- [ ] Measure ZMCT103C burden resistor value with 5A/10A loads
- [ ] Verify ZMPT101B module output range (0–5V or 0–3.3V)
- [ ] Confirm MC-38 door sensor NO/NC wiring
- [ ] Validate 74HC595 vs 74HCT595 choice (3.3V logic)
- [ ] Verify 1N5817 diode orientation: anode to 74HC595, cathode to relay node (8×)
- [ ] Confirm DIP switch (SW1) position order: position 1 → Relay CH1 … position 8 → Relay CH8
- [ ] Confirm DIP switch low-side pins (positions 1–8) tied to GND
- [ ] Confirm 30A relay bypass (NO push button or spare DIP position to GND)
- [ ] Confirm PCA9685 address pins (A0/A1) for 0x40
- [ ] Check LEDC channel availability (10 channels needed)
- [ ] Verify all strapping pins safe for assigned PWM use
- [ ] Confirm NO external pull-up/pulldown added on ready module inputs (PCA9685 OE, relay + 30A modules, D4814 triggers)
- [ ] Validate I2C bus length < 30cm, proper pull-ups
- [ ] Confirm 30A relay module 3.3V logic compatibility

---

## 11. Revision History

| Date | Revision | Description |
|---|---|---|
| 2024-01-15 | 1.0 | Initial production design guide |
| 2024-01-20 | 1.1 | Updated GPIO map per fresh production assignment |
| 2024-01-22 | 1.2 | Finalized 10 ESP32 LEDC + 14 PCA9685 PWM channels |
| 2024-01-24 | 1.3 | Added relay manual override/bypass (§4A): 8× 1N5817 diodes, DIP position 1→Relay CH1 order, DIP low-pin GND tie, 30A relay bypass |
| 2024-01-25 | 1.4 | Corrected PWM transport per SPECIFICATIONS.md: 10 ESP32 LEDC (6 CCT on high-speed CH0–5 + Photo Spot/Wall Bounce/Washroom/Terrace) + 14 PCA9685 CH0–13 + BACKUP_01/02 (CH14–15); removed CEILING_COLD duplication and GPIO17 misuse |
| 2024-01-26 | 1.5 | Removed external pull-up/pulldown networks on ready modules (PCA9685 OE strapped LOW = always enabled; 8-ch + 30A relay modules have internal input circuits; D4814 trigger modules fail-safe OFF); corrected Section 1 GPIO map to the approved CCT-grouped allocation |

---

*This document and pin-budget.md are the authoritative sources for schematic capture and PCB layout.*

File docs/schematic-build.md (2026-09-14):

# AutoMate Schematic Build Checklist (KiCad GUI)

> **Purpose:** Step-by-step guide to assemble the `AutoMate_Rebuild` schematic in the KiCad GUI.
> **Method:** Option B — user places component symbols and draws pin-to-pin wires in KiCad; AI added wires/labels/validation are limited by the MCP server not resolving symbol libraries, so connectivity is drawn in the GUI and validated afterward with netlist + ERC/DRC.
> **Source of truth:** SPECIFICATIONS.md, docs/pin-budget.md, PCB_DESIGN_GUIDE.md
> **Blocked on:** symbol-library import (see §0) before components can be placed.

---

## 0. One-time symbol-library setup (before placing parts)

The MCP toolchain and KiCad need the parts registered as KiCad symbol/footprint libraries. Parts downloaded from the registry live in `/Users/reubenvanka/Documents/iot-workspace/KiCad_Assets/` as `.kicad_sym` / `.kicad_mod` / `.step` but are **not yet imported**.

1. Open KiCad → Schematic editor → **Add Symbol** (or the symbol browser).
2. Import each `.kicad_sym` into a symbol library (e.g., a new `AutoMate` library):
   - `KiCad_Assets/1N5817/1N5817.kicad_sym`
   - `KiCad_Assets/ESP32-DEVKITC/MODULE_ESP32-DEVKITC.kicad_sym`
   - `KiCad_Assets/74HC595N_112/74HC595N_112.kicad_sym`
3. Ensure a `sym-lib-table` for the project references these so they resolve on the sheet.

---

## 1. Component placement (suggested grid — A3 landscape)

| Ref | Component | Suggested (x, y) mm | Library : Symbol |
|-----|---|---|---|
| U1 | ESP32-WROOM-32E DevKit | (80, 150) | `snapeda:MODULE_ESP32-DEVKITC` |
| U2 | 74HC595 shift register | (165, 145) | `74xx:74HC595` |
| D1–D8 | 1N5817 Schottky diodes | (150–200, 95) | `AutoMate:1N5817` (imported) |
| SW1 | 12-position DIP switch | (165, 70) | `Switch:SW_DIP_x12` |
| J5 | Relay connector (1×10) | (230, 120) | `Connector:Conn_01x10_Socket` |
| J2_PCA9685 | PCA9685 connector (1×6) | (60, 210) | `Connector:Conn_01x06_Socket` |
| J11 | Door sensor conn (1×2) | (115, 230) | `Connector:Conn_01x02_Socket` |
| J9 | ZMPT conn (1×4) | (150, 230) | `Connector:Conn_01x04_Socket` |
| VoltageSen1 | Voltage sensor conn (1×3) | (185, 230) | `Connector:Conn_01x03_Socket` |
| J1 | RJ45 / cable conn | (230, 190) | `8P8C` (RJ45) |
| AC1 | AC input | (260, 210) | `Conn_01x03_Socket` |
| T1–T6 | Screw terminals | (230–280, 230) | `Screw_Terminal_01x02` |
| F1 | Fuse | (245, 200) | `Polyfuse` |
| M1–M10 | Dual MOSFET modules | lower band | `00.snapeda:D4184 Module Custom Updated` |

*(Coordinates are suggestions; place symbols by clicking in KiCad. Only SW1/U2/J5/D1–D8 positions matter for wiring below.)*

---

## 2. Wiring / connectivity (pin-by-pin)

### 2.1 ESP32 → sensors / outputs (GPIO map)

Wire each ESP32 GPIO leg to its destination. Save label net names per `docs/pin-budget.md`.

| From (ESP32 pin) | To | Net name (label) |
|---|----|---|
| GPIO0 | — (free — no OE gate; module strapped low) | — |
| GPIO0 | U2 SER | `SER` |
| GPIO23 | U2 SRCLK | `SRCLK` |
| GPIO15 | U2 RCLK | `RCLK` |
| GPIO21 | J2_PCA9685 + sensors SDA | `I2C_SDA` |
| GPIO22 | J2_PCA9685 + sensors SCL | `I2C_SCL` |
| GPIO34 | ADC1 (ZMCT103C) | `ZMCT103C_CURRENT` |
| GPIO35 | ADC1 (ZMPT101B) | `ZMPT101B_VOLTAGE` |
| GPIO14 | door sensor (J11) | `DOOR_SENSOR` |
| GPIO39 | IR receiver | `IR_RX` |
| GPIO32 | 30A relay bypass | `RELAY_30A` |

### 2.2 74HC595 → 1N5817 diodes → DIP switch → J5 (relays)

Insert **1N5817** (anode to 74HC595, cathode to relay node) between each 74HC595 output and the DIP high pin. DIP low pin → GND.

| Relay CH | 74HC595 U2 out | J5 pin | DIP high pin (→ relay node) | DIP low pin (→ GND) |
|---|---|---|---|---|
| CH1 | U2-15 | J5-2 | SW1-13 | SW1-1 |
| CH2 | U2-1 | J5-3 | SW1-14 | SW1-2 |
| CH3 | U2-2 | J5-4 | SW1-15 | SW1-3 |
| CH4 | U2-3 | J5-5 | SW1-16 | SW1-4 |
| CH5 | U2-4 | J5-6 | SW1-17 | SW1-5 |
| CH6 | U2-5 | J5-7 | SW1-18 | SW1-6 |
| CH7 | U2-6 | J5-8 | SW1-19 | SW1-7 |
| CH8 | U2-7 | J5-9 | SW1-20 | SW1-8 |

- 74HC595 control legs: SER (U2-14) → GPIO0; SRCLK (U2-11) → GPIO23; RCLK (U2-12) → GPIO15; OE (U2-13) → GND; SRCLR (U2-10) → 3.3V via 10kΩ; VCC (U2-16) → 3.3V; GND (U2-8) → GND.
- J5-P10 → +5V (relay module VCC). J5-P1 → GND.

### 2.3 Power rails

Wire shared nets: `+5V`, `3.3V`, `GND`.

| From | To | Net |
|---|----|-----|
| +5V bus | J5-P10, J2_PCA9685-Px, ZMPT101B, PCA9685 VCC | `+5V` |
| GND | U1 GND, U2-8, J5-P1, J2_PCA9685, all M1–M10 | `GND` |
| 3.3V | U2-16 (VCC), SRCLR control, I2C pull-ups (verify), 1N5817 diode nodes | `3.3V` |
### 2.4 PWM — 10 ESP32 LEDC channels

All 10 LEDC channels at 10 kHz. No external pull-down (D4814 modules fail-safe OFF). CCT pairs on adjacent pins.

| # | Function | ESP32 GPIO | Notes |
|---|---|---|---|
| 1 | CEILING_WARM | GPIO18 | CCT pair (high-speed CH0) |
| 2 | CEILING_COLD | GPIO19 | CCT pair (high-speed CH1) |
| 3 | DESK1_WARM | GPIO25 | CCT pair (CH2) |
| 4 | DESK1_COLD | GPIO26 | CCT pair (CH3) |
| 5 | DESK2_WARM | GPIO4 | CCT pair (CH4, strapping) |
| 6 | DESK2_COLD | GPIO5 | CCT pair (CH5, strapping) |
| 7 | PHOTO_SPOT_LIGHT | GPIO12 | single |
| 8 | WALL_BOUNCE_LIGHT | GPIO13 | single |
| 9 | WASHROOM_LIGHT | GPIO33 | single |
| 10 | TERRACE_LIGHT | GPIO27 | single |

### 2.5 PWM — 14 PCA9685 channels (32 + 2 backup)

PCA9685 @0x40, driven over I2C (GPIO21 SDA / GPIO22 SCL). OE is strapped LOW in the module (outputs always enabled). All at 1 kHz. Backups (CH14/CH15) are **named, not unassigned** — keep them assigned so future devices map without restructuring.

| PCA9685 CH | Function |
|---|---|
| CH0 | MONITOR1_BACKLIGHT |
| CH1 | DESK_LIGHT1 |
| CH2 | TABLE_LIGHT |
| CH3 | SHELF_LIGHT1 |
| CH4 | MONITOR2_BACKLIGHT |
| CH5 | DESK_LIGHT2 |
| CH6 | SHELF_LIGHT2 |
| CH7 | CUPBOARD_BOUNCE_LIGHT |
| CH8 | CUPBOARD_SPOT_LIGHT |
| CH9 | DOOR_SPOT_LIGHT |
| CH10 | MONITOR3_BACKLIGHT |
| CH11 | MONITOR4_BACKLIGHT |
| CH12 | EXHAUST_FANS (shared) |
| CH13 | TERRACE_AMBIENT_LIGHT |
| CH14 | BACKUP_01 (reserved) |
| CH15 | BACKUP_02 (reserved) |

Wire each PCA9685 channel output leg to the corresponding load. Do not leave CH14/CH15 floating unassigned — terminate the net with a BACKUP_01 / BACKUP_02 label.

---

## 3. Connection labels to add (KiCad "Connection/GMD" fields)

Label these nets so connectivity is legible:
`+5V`, `3.3V`, `GND`, `I2C_SDA`, `I2C_SCL`, `SER`, `SRCLK`, `RCLK`, `ZMCT103C_CURRENT`, `ZMPT101B_VOLTAGE`, `DOOR_SENSOR`, `IR_RX`, `RELAY_30A`, and the 24 PWM nets: `CEILING_WARM`, `CEILING_COLD`, `DESK1_WARM`, `DESK1_COLD`, `DESK2_WARM`, `DESK2_COLD`, `PHOTO_SPOT_LIGHT`, `WALL_BOUNCE_LIGHT`, `WASHROOM_LIGHT`, `TERRACE_LIGHT`, `MONITOR1_BACKLIGHT`, `DESK_LIGHT1`, `TABLE_LIGHT`, `SHELF_LIGHT1`, `MONITOR2_BACKLIGHT`, `DESK_LIGHT2`, `SHELF_LIGHT2`, `CUPBOARD_BOUNCE_LIGHT`, `CUPBOARD_SPOT_LIGHT`, `DOOR_SPOT_LIGHT`, `MONITOR3_BACKLIGHT`, `MONITOR4_BACKLIGHT`, `EXHAUST_FANS`, `TERRACE_AMBIENT_LIGHT`, plus `BACKUP_01`, `BACKUP_02`.

---

## 4. Validation (after wiring)

Once placed and wired in KiCad, I will run:
1. `generate_netlist` → export `/tmp` netlist
2. `get_netlist_nets` + `trace_netlist_connection` → check all 13 signal nets + rails present
3. `run_erc` → Electrical Rules Check (unconnected pins, conflicts)
4. After PCB layout: `run_drc` + `export_erc_report` / `export_drc_report`

Record results in `docs/release-evidence.md` per Gate 4.

---

*Source of truth cross-refs: docs/pin-budget.md §2–§6, PCB_DESIGN_GUIDE.md §4A.*

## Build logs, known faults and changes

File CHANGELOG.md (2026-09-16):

# AutoMate IOT Project - CHANGELOG

## [2026-09-16] - Version 1.0.0 (firmware-v0.1.2 based)
### Initial working version restored from firmware-v0.1.2 tag
- Restored all packages from firmware-v0.1.2 tag (core.yaml, pwm.yaml, pca9685.yaml, relays.yaml)
- Base configuration with:
  - 9 relays via 74HC595 + 1 direct 30A relay
  - 10 LEDC PWM outputs (2 CCT ceiling, 2 CCT desk1, 2 CCT desk2, 4 monochromatic)
  - 14 PCA9685 monochromatic lights
  - Template switches for all relays
  - Binary sensor automations for:
    - non_ceiling_pwm_active (12V driver)
    - ceiling_pwm_active (ceiling driver)
    - desks_active (voltage stabilizer)
  - Web server with auth, captive portal, OTA
  - NVS preferences with 30s write interval
  - Basic boot sequence (no state restoration)

---

## [2026-09-16] - Version 1.0.1
### Added state persistence and immediate NVS writes
- Changed `flash_write_interval: 30s` → `0s` for immediate NVS writes
- Added globals for relay state persistence (fan, ceiling_driver, 12v_driver, stabilizer, desk1-3, 16a, 30a)
- Added globals for light state persistence (ceiling, desk1, desk2, photo_spot, wall_bounce, terrace, washroom)
- Added boot state restoration logic in core.yaml
- Added state saving on light/relay changes
- Fixed template switches to read from physical relays (`.state`)
- Changed template switch actions to use `switch.turn_on/off` instead of `output.turn_on/off`
- Set all physical relays as `internal: true` (hidden from HA)
- Added `on_turn_on/off` handlers to all lights to save state immediately
- Fixed non_ceiling_pwm_active to include all non-ceiling lights
- Added desk1/desk2 prev_state globals to pwm.yaml

---

## [2026-09-16] - Version 1.0.2
### Fixed 12V driver automation and added PCA9685 light state persistence
- Added `desk1_prev_state`, `desk2_prev_state` globals to pwm.yaml (with restore_value: yes)
- Added `desk3_prev_state` global to relays.yaml (desk3 relay exists but no CCT light)
- Fixed `non_ceiling_pwm_active` binary sensor to include ALL non-ceiling lights:
  - Desk CCT lights (desk1, desk2)
  - LEDC monochromatic (photo_spot, wall_bounce, terrace, washroom)
  - PCA9685 monochromatic (monitor backlights, desk lights, table, shelf lights, cupboard, door, exhaust, terrace_ambient)
- Added `on_turn_on`/`on_turn_off` handlers to ALL PCA9685 lights to control 12V driver
- Added `on_state` handlers to ALL PCA9685 lights to save state immediately
- Added globals for all PCA9685 lights (state + brightness)
- Fixed output IDs in PCA9685 lights (added missing `_light` suffixes)
- Fixed desk3_prev_state global in relays.yaml (needed for desk3 relay)

---

## [2026-09-16] - Version 1.0.3
### Fixed 12V driver last state restoration
- Added `desk1_prev_state`, `desk2_prev_state` globals with `restore_value: yes`
- Added `desk3_prev_state` global to relays.yaml with `restore_value: yes`
- Removed desk1/desk2 prev_state from relays.yaml (only in pwm.yaml)
- Fixed relay state restoration in boot sequence
- Fixed immediate NVS writes (`flash_write_interval: 0s`)
- Ensured all state changes save immediately to NVS
- Fixed 12V driver automation to use `switch.turn_on/off` consistently
- Added state saving in `on_state` for all lights (real-time persistence)

### Files Modified:
- `packages/core.yaml` - Boot restoration, NVS settings, flash_write_interval
- `packages/relays.yaml` - Globals, internal relays, template switches, automations
- `packages/pwm.yaml` - Light globals, light handlers, desk state globals
- `packages/pca9685.yaml` - All 16 PCA9685 lights with on_turn_on/off and state saving

---

## Versioning Scheme
- **Major**: Breaking changes, hardware changes
- **Minor**: New features, significant fixes
- **Patch**: Bug fixes, small improvements

---

## Backup Location
All firmware binaries are stored in:
- `.esphome/build/automate/.pioenvs/automate/firmware.bin`
- `.esphome/build/automate/.pioenvs/automate/firmware.factory.bin`
- `.esphome/build/automate/.pioenvs/automate/firmware.ota.bin`

Git tags used for versioning:
- `firmware-v0.1.0` - Initial compilable assembly
- `firmware-v0.1.1` - GPIO fix
- `firmware-v0.1.2` - Health monitoring + activity LED + DHCP (working baseline)
- Current working directory state tracked via git commits

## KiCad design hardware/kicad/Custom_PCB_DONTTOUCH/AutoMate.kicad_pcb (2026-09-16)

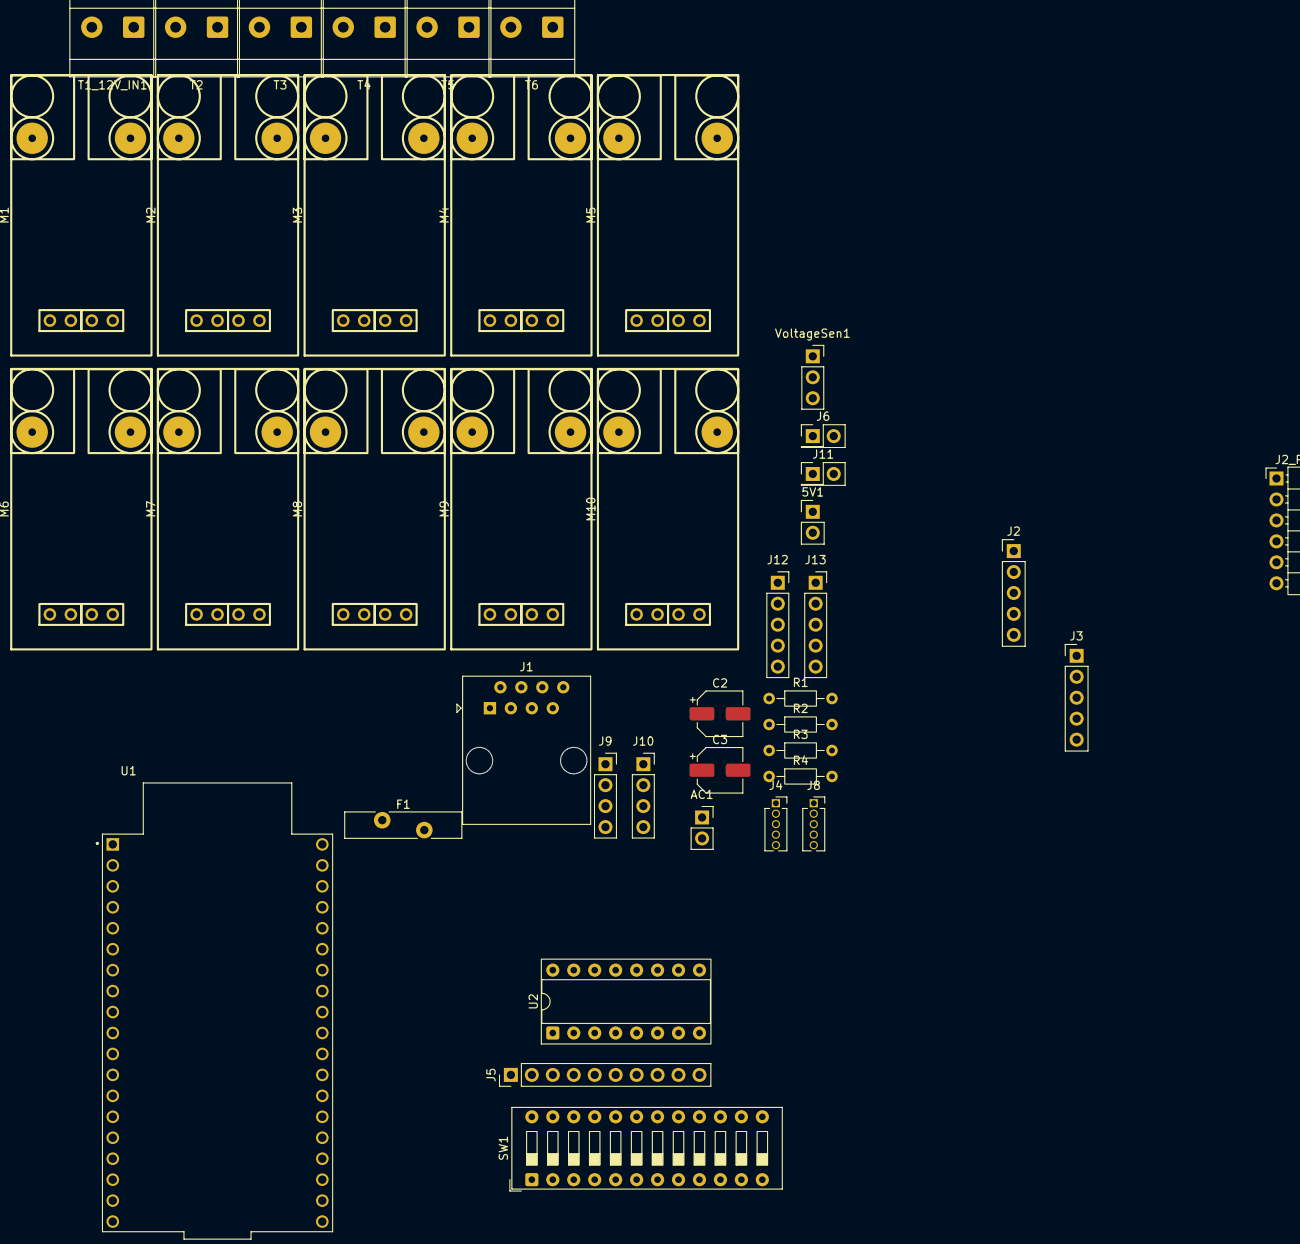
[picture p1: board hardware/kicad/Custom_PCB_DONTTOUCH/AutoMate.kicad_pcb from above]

Board: 8 copper layers, 42 parts (0 on the bottom side), 24 nets, no tracks yet.

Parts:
5V1: GND; PinHeader_1x02_P2.54mm_Vertical
AC1: PinSocket_1x02_P2.54mm_Vertical
C2: 100nF; CP_Elec_5x3.9
C3: 470uf; CP_Elec_5x3.9
F1: Polyfuse; Fuse_Bourns_MF-RHT700
J1: 8P8C; RJ45_Amphenol_54602-x08_Horizontal
J2: SDA; PinHeader_1x05_P2.54mm_Vertical
J2_PCA9685: PCA9685; PinHeader_1x06_P2.54mm_Horizontal
J3: SCL; PinHeader_1x05_P2.54mm_Vertical
J4: +5V; PinSocket_1x05_P1.27mm_Vertical
J5: Relay; PinHeader_1x10_P2.54mm_Vertical
J6: tx rx; PinHeader_2x01_P2.54mm_Vertical
J8: GND; PinSocket_1x05_P1.27mm_Vertical
J9: ZMPT; PinSocket_1x04_P2.54mm_Vertical
J10: Sensors all; PinSocket_1x04_P2.54mm_Vertical
J11: Door Sensor; PinHeader_2x01_P2.54mm_Vertical
J12: a; PinSocket_1x05_P2.54mm_Vertical
J13: Rst-boot-led-ws2812b-3.3v; PinSocket_1x05_P2.54mm_Vertical
M1, M2, M3, M4, M5, M6, M7, M8, M9, M10: D4184 Module Custom Updated
R1, R3: 4.7k Pull-up SDA/SCL; R_Axial_DIN0204_L3.6mm_D1.6mm_P7.62mm_Horizontal
R2: 1k Ohm; R_Axial_DIN0204_L3.6mm_D1.6mm_P7.62mm_Horizontal
R4: 10k Pull-Down; R_Axial_DIN0204_L3.6mm_D1.6mm_P7.62mm_Horizontal
SW1: SW_DIP_x12; SW_DIP_SPSTx12_Slide_9.78x32.66mm_W7.62mm_P2.54mm
T1_12V_IN1, T2, T3, T4, T5, T6: Screw_Terminal_01x02; TerminalBlock_Phoenix_MKDS-3-2-5.08_1x02_P5.08mm_Horizontal
U1: ESP32-DEVKITC; MODULE_ESP32-DEVKITC
U2: 74HC595; DIP-16_W7.62mm_Socket
VoltageSen1: PinSocket_1x03_P2.54mm_Vertical

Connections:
04 PWM/Relay-WS2812b: J1.3, J13.2, R4.1
16 PWM/Relay/rx2: J1.6, J6.2, R2.2
17 PWM/Relay/tx2: J1.5, J6.1
21 SDA: J1.1, J2.1, J2.2, J2.3, J2.4, J2.5, R3.1
22 SCL: J1.8, J3.1, J3.2, J3.3, J3.4, J3.5, R1.1
34 IP_ONLY: J9.2, J10.3
35 IP_ONLY: J10.4, VoltageSen1.2
36 IP_ONLY: J10.1, J11.2
+3.3V: J1.7, J13.1, U1.1 (3V3)
+5V: AC1.1, C2.2, C3.2, F1.1, J1.4, J4.1, J4.2, J4.3, J4.4, J4.5, J5.10, J9.1, R1.2, R3.2, R4.2, VoltageSen1.1
GND: 5V1.2 (-), AC1.2, C2.1, C3.1, J1.2, J2_PCA9685.1, J5.1, J8.1, J8.2, J8.3, J8.4, J8.5, J9.3, J9.4, J11.1, J12.5, M1.4 (GND), M2.4 (GND), M3.4 (GND_4), M4.4 (GND_4), M5.4 (GND_4), M6.4 (GND_4), M7.4 (GND_4), M8.4 (GND_4), M9.4 (GND_4), M10.4 (GND_4), U1.38 (GND3), VoltageSen1.3
unnamed: 5V1.1 (+), F1.2
unnamed: J5.2, SW1.24, U2.15 (QA)
unnamed: J5.3, SW1.23, U2.1 (QB)
unnamed: J5.4, SW1.22, U2.2 (QC)
unnamed: J5.5, SW1.21, U2.3 (QD)
unnamed: J5.6, SW1.20, U2.4 (QE)
unnamed: J5.7, SW1.19, U2.5 (QF)
unnamed: J5.8, SW1.18, U2.6 (QG)
unnamed: J5.9, SW1.17, U2.7 (QH)
unnamed: SW1.1, SW1.2, SW1.3, SW1.4, SW1.5, SW1.6, SW1.7, SW1.8, SW1.9, SW1.10, SW1.11, SW1.12
PCA9685_OE (with 10kΩ pull-up to 3.3V): J2_PCA9685.2, U1.25 (IO0)
PWM_CEILING_COLD: M2.1 (PWM), U1.34 (RXD0)
PWM_CEILING_WARM: M1.1 (PWM), U1.35 (TXD0)

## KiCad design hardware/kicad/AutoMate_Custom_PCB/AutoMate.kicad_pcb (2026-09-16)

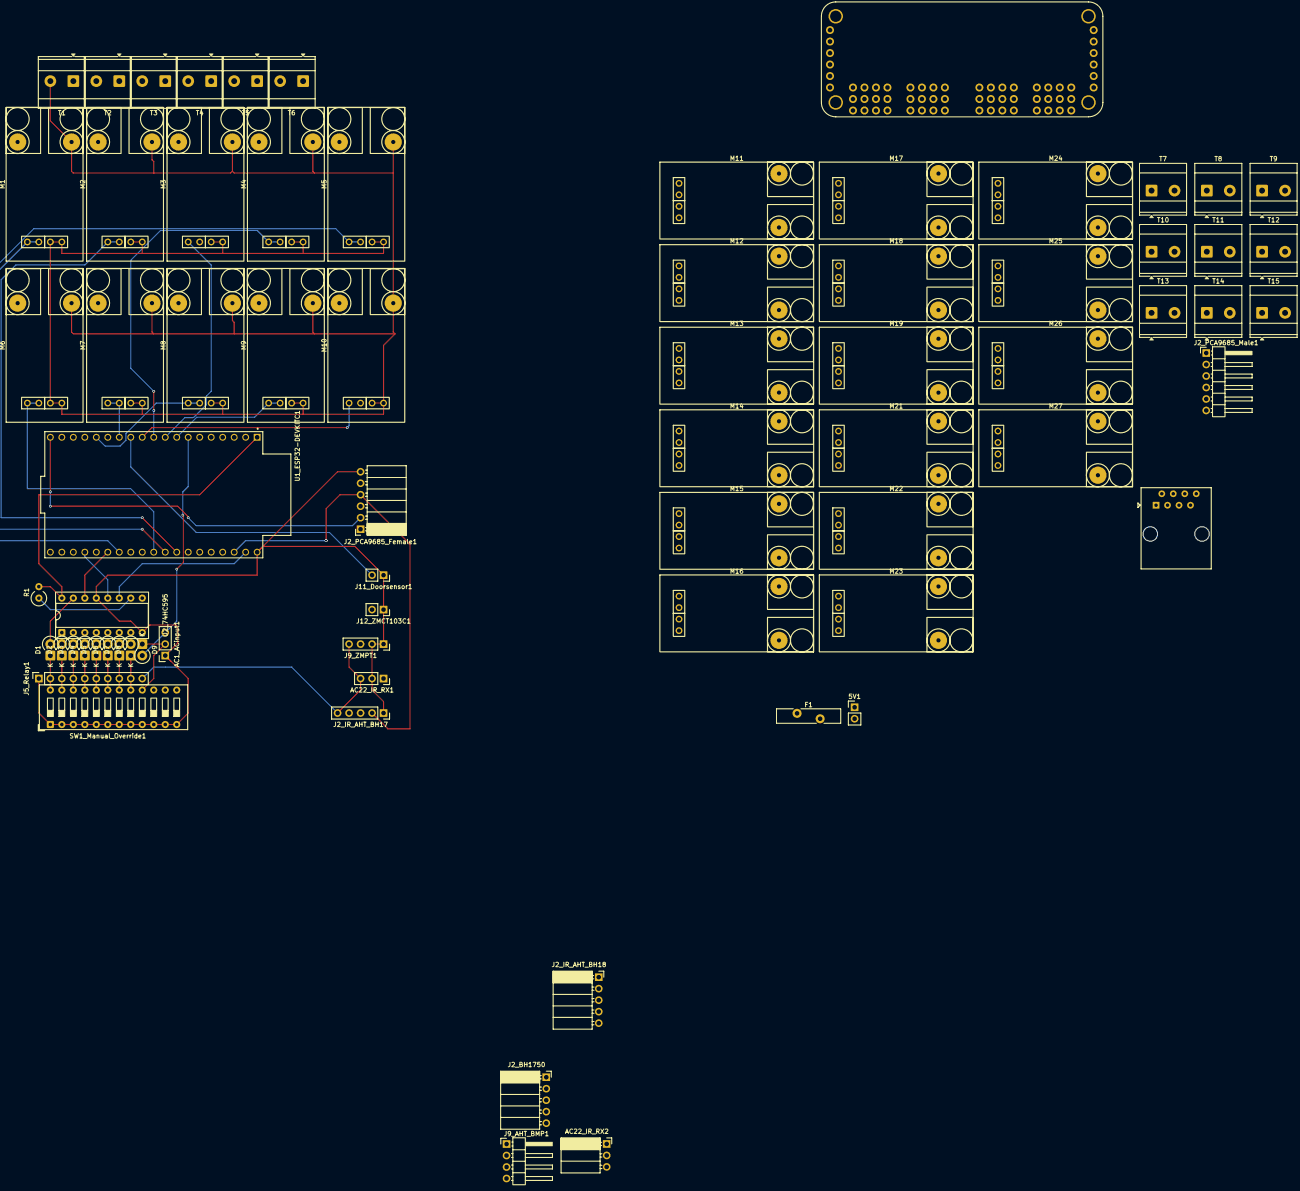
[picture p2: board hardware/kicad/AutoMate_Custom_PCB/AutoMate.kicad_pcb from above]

Board: 8 copper layers, 71 parts (0 on the bottom side), 85 nets.

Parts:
5V1: GND; PinHeader_1x02_P2.54mm_Vertical
AC1_ACinput1, AC22_IR_RX1: Conn_01x03_Socket; PinSocket_1x03_P2.54mm_Vertical
AC22_IR_RX2: Conn_01x03_Socket; PinSocket_1x03_P2.54mm_Horizontal
D1, D2, D3, D4, D5, D6, D7, D8, D9: 1N5817; D_DO-41_SOD81_P2.54mm_Vertical_CathodeUp
F1: Polyfuse; Fuse_Bourns_MF-RHT700
J1: 8P8C; RJ45_Amphenol_54602-x08_Horizontal
J2_BH1750, J2_IR_AHT_BH18: Conn_01x05_Socket; PinSocket_1x05_P2.54mm_Horizontal
J2_IR_AHT_BH17: Conn_01x05_Socket; PinSocket_1x05_P2.54mm_Vertical
J2_PCA9685_Female1: PCA9685; PinSocket_1x06_P2.54mm_Horizontal
J2_PCA9685_Male1: PCA9685; PinHeader_1x06_P2.54mm_Horizontal
J5_Relay1: Relay; PinSocket_1x10_P2.54mm_Vertical
J9_AHT_BMP1: Conn_01x04_Socket; PinHeader_1x04_P2.54mm_Horizontal
J9_ZMPT1: Conn_01x04_Socket; PinSocket_1x04_P2.54mm_Vertical
J11_Doorsensor1, J12_ZMCT103C1: Conn_01x02_Socket; PinSocket_1x02_P2.54mm_Vertical
M1, M2, M3, M4, M5, M6, M7, M8, M9, M10, M11, M12, M13, M14, M15, M16, M17, M18, M19, M21, M22, M23, M24, M25, M26, M27: D4184 Module Custom Updated
R1: 10k; R_Axial_DIN0309_L9.0mm_D3.2mm_P2.54mm_Vertical
SW1_Manual_Override1: SW_DIP_x12; SW_DIP_SPSTx12_Slide_9.78x32.66mm_W7.62mm_P2.54mm
T1, T2, T3, T4, T5, T6, T7: Screw_Terminal_01x02; TerminalBlock_Phoenix_MKDS-3-2-5.08_1x02_P5.08mm_Horizontal
T8, T9, T10, T11, T12, T13, T14, T15: ST01x02; TerminalBlock_Phoenix_MKDS-3-2-5.08_1x02_P5.08mm_Horizontal
U1: 815; MODULE_815_pca9685
U1_ESP32-DEVKITC1: ESP32-DEVKITC; MODULE_ESP32-DEVKITC
U2_74HC595: 74HC595; DIP-16_W7.62mm_Socket

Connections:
30A_JN: AC1_ACinput1.3, D9.1, SW1_Manual_Override1.16
+3.3V: J1.7, R1.2, U1_ESP32-DEVKITC1.1 (3V3), U2_74HC595.16 (VCC)
+5V: AC1_ACinput1.1, AC22_IR_RX1.3, AC22_IR_RX2.3, F1.1, J1.4, J2_BH1750.5, J2_IR_AHT_BH17.5, J2_IR_AHT_BH18.5, J2_PCA9685_Female1.2, J2_PCA9685_Male1.5, J5_Relay1.10, J9_AHT_BMP1.1, J9_ZMPT1.4, U1.VCC_1 (VCC), U1.VCC_2 (VCC), U1_ESP32-DEVKITC1.19 (EXT_5V)
+12V: T1.1, T7.1
BACKUP_01: M26.1 (PWM), M26.2 (PWM), U1.14 (PWM_14)
BACKUP_02: M27.1 (PWM), M27.2 (PWM), U1.15 (PWM_15)
BU1: M26.5 (Led), T15.1
BU2: M27.5 (Led), T15.2
CBL: M18.5 (Led), T11.2
CC: M2.5 (Led), T2.2
CEILING_COLD: M2.1 (PWM), M2.2 (PWM), U1_ESP32-DEVKITC1.31 (IO19)
CEILING_WARM: M1.1 (PWM), M1.2 (PWM), U1_ESP32-DEVKITC1.30 (IO18)
CSL: M19.5 (Led), T12.1
CUPBOARD_BOUNCE_LIGHT: M18.1 (PWM), M18.2 (PWM), U1.7 (PWM_7)
CUPBOARD_SPOT_LIGHT: M19.1 (PWM), M19.2 (PWM), U1.8 (PWM_8)
CW: M1.5 (Led), T2.1
D1C: M4.5 (Led), T3.2
D1W: M3.5 (Led), T3.1
D2C: M6.5 (Led), T4.2
D2W: M5.5 (Led), T4.1
DESK1_COLD: M4.1 (PWM), M4.2 (PWM), U1_ESP32-DEVKITC1.10 (IO26)
DESK1_WARM: M3.1 (PWM), M3.2 (PWM), U1_ESP32-DEVKITC1.9 (IO25)
DESK2_COLD: M6.1 (PWM), M6.2 (PWM), U1_ESP32-DEVKITC1.29 (IO5)
DESK2_WARM: M5.1 (PWM), M5.2 (PWM), U1_ESP32-DEVKITC1.26 (IO4)
DESK_LIGHT1: M12.1 (PWM), M12.2 (PWM), U1.1 (PWM_1)
DESK_LIGHT2: M16.1 (PWM), M16.2 (PWM), U1.5 (PWM_5)
DL1: M12.5 (Led), T8.2
DL2: M16.5 (Led), T10.2
DOOR_SENSOR: J11_Doorsensor1.2, U1_ESP32-DEVKITC1.12 (IO14)
DOOR_SPOT_LIGHT: M21.1 (PWM), M21.2 (PWM), U1.9 (PWM_9)
DSL: M21.5 (Led), T12.2
EF: M24.5 (Led), T14.1
EXHAUST_FANS: M24.1 (PWM), M24.2 (PWM), U1.12 (PWM_12)
GND: 5V1.2 (-), AC1_ACinput1.2, AC22_IR_RX1.2, AC22_IR_RX2.2, J1.2, J2_BH1750.1, J2_IR_AHT_BH17.1, J2_IR_AHT_BH18.1, J2_PCA9685_Female1.6, J2_PCA9685_Male1.1, J5_Relay1.1, J9_AHT_BMP1.3, J9_ZMPT1.1, J9_ZMPT1.2, J11_Doorsensor1.1, J12_ZMCT103C1.1, M1.3 (GND), M1.4 (GND), M1.6 (Gnd), M2.3 (GND), M2.4 (GND), M2.6 (Gnd), M3.3 (GND), M3.4 (GND), M3.6 (Gnd), M4.3 (GND), M4.4 (GND), M4.6 (Gnd), M5.3 (GND), M5.4 (GND), M5.6 (Gnd), M6.3 (GND), M6.4 (GND), M6.6 (Gnd), M7.3 (GND), M7.4 (GND), M7.6 (Gnd), M8.3 (GND), M8.4 (GND), M8.6 (Gnd), M9.3 (GND), M9.4 (GND), M9.6 (Gnd), M10.3 (GND), M10.4 (GND), M10.6 (Gnd), M11.3 (GND), M11.4 (GND), M11.6 (Gnd), M12.3 (GND), M12.4 (GND), M12.6 (Gnd), M13.3 (GND), M13.4 (GND), M13.6 (Gnd), M14.3 (GND), M14.4 (GND), M14.6 (Gnd), M15.3 (GND), M15.4 (GND), M15.6 (Gnd), M16.3 (GND), M16.4 (GND), M16.6 (Gnd), M17.3 (GND), M17.4 (GND), M17.6 (Gnd), M18.3 (GND), M18.4 (GND), M18.6 (Gnd), M19.3 (GND), M19.4 (GND), M19.6 (Gnd), M21.3 (GND), M21.4 (GND), M21.6 (Gnd), M22.3 (GND), M22.4 (GND), M22.6 (Gnd), M23.3 (GND), M23.4 (GND), M23.6 (Gnd), M24.3 (GND), M24.4 (GND), M24.6 (Gnd), M25.3 (GND), M25.4 (GND), M25.6 (Gnd), M26.3 (GND), M26.4 (GND), M26.6 (Gnd), M27.3 (GND), M27.4 (GND), M27.6 (Gnd), SW1_Manual_Override1.1, SW1_Manual_Override1.2, SW1_Manual_Override1.3, SW1_Manual_Override1.4, SW1_Manual_Override1.5, SW1_Manual_Override1.6, SW1_Manual_Override1.7, SW1_Manual_Override1.8, SW1_Manual_Override1.9, SW1_Manual_Override1.10, SW1_Manual_Override1.11, SW1_Manual_Override1.12, T1.2, T7.2, U1.GND_1 (GND), U1.GND_2 (GND), U1.GND_3 (GND), U1.GND_4 (GND), U1.GND_5 (GND), U1.GND_6 (GND), U1.GND_7 (GND), U1.GND_8 (GND), U1.GND_9 (GND), U1.GND_10 (GND), U1.GND_11 (GND), U1.GND_12 (GND), U1.GND_13 (GND), U1.GND_14 (GND), U1.GND_15 (GND), U1.GND_16 (GND), U1.GND_17 (GND), U1.GND_18 (GND), U1_ESP32-DEVKITC1.38 (GND3), U2_74HC595.8 (GND), U2_74HC595.13 (~OE)
I2C_SCL: J2_BH1750.4, J2_IR_AHT_BH17.2, J2_IR_AHT_BH18.2, J2_PCA9685_Female1.4, J2_PCA9685_Male1.3, J9_AHT_BMP1.4, U1.SCL_1 (SCL), U1.SCL_2 (SCL), U1_ESP32-DEVKITC1.36 (IO22)
I2C_SDA: J2_BH1750.3, J2_IR_AHT_BH17.3, J2_IR_AHT_BH18.3, J2_PCA9685_Female1.3, J2_PCA9685_Male1.4, J9_AHT_BMP1.2, U1.SDA_1 (SDA), U1.SDA_2 (SDA), U1_ESP32-DEVKITC1.33 (IO21)
IR_RX: AC22_IR_RX1.1, AC22_IR_RX2.1, J2_IR_AHT_BH17.4, J2_IR_AHT_BH18.4, U1_ESP32-DEVKITC1.4 (SENSOR_VN)
M1B: M11.5 (Led), T8.1
M2B: M15.5 (Led), T10.1
M3B: M22.5 (Led), T13.1
M4B: M23.5 (Led), T13.2
MONITOR1_BACKLIGHT: M11.1 (PWM), M11.2 (PWM), U1.0 (PWM_0)
MONITOR2_BACKLIGHT: M15.1 (PWM), M15.2 (PWM), U1.4 (PWM_4)
MONITOR3_BACKLIGHT: M22.1 (PWM), M22.2 (PWM), U1.10 (PWM_10)
MONITOR4_BACKLIGHT: M23.1 (PWM), M23.2 (PWM), U1.11 (PWM_11)
unnamed: 5V1.1 (+), F1.2
unnamed: D1.1, J5_Relay1.2, SW1_Manual_Override1.24
unnamed: D2.1, J5_Relay1.3, SW1_Manual_Override1.23
unnamed: D3.1, J5_Relay1.4, SW1_Manual_Override1.22
unnamed: D4.1, J5_Relay1.5, SW1_Manual_Override1.21
unnamed: D5.1, J5_Relay1.6, SW1_Manual_Override1.20
unnamed: D6.1, J5_Relay1.7, SW1_Manual_Override1.19
unnamed: D7.1, J5_Relay1.8, SW1_Manual_Override1.18
unnamed: D8.1, J5_Relay1.9, SW1_Manual_Override1.17
unnamed: D1.2, U2_74HC595.15 (QA)
unnamed: D2.2, U2_74HC595.1 (QB)
unnamed: D3.2, U2_74HC595.2 (QC)
unnamed: D4.2, U2_74HC595.3 (QD)
unnamed: D5.2, U2_74HC595.4 (QE)
unnamed: D6.2, U2_74HC595.5 (QF)
unnamed: D7.2, U2_74HC595.6 (QG)
unnamed: D8.2, U2_74HC595.7 (QH)
unnamed: R1.1, U2_74HC595.10 (~SRCLR)
PHOTO_SPOT_LIGHT: M7.1 (PWM), M7.2 (PWM), U1_ESP32-DEVKITC1.13 (IO12)
PSL: M8.5 (Led), T5.2
RCLK: U1_ESP32-DEVKITC1.23 (IO15), U2_74HC595.12 (RCLK)
RELAY_30A: D9.2, U1_ESP32-DEVKITC1.7 (IO32)
SER: U1_ESP32-DEVKITC1.25 (IO0), U2_74HC595.14 (SER)
SHELF_LIGHT1: M14.1 (PWM), M14.2 (PWM), U1.3 (PWM_3)
SHELF_LIGHT2: M17.1 (PWM), M17.2 (PWM), U1.6 (PWM_6)
SHL1: M14.5 (Led), T9.2
SHL2: M17.5 (Led), T11.1
SRCLK: U1_ESP32-DEVKITC1.37 (IO23), U2_74HC595.11 (SRCLK)
TABLE_LIGHT: M13.1 (PWM), M13.2 (PWM), U1.2 (PWM_2)
TAL: M25.5 (Led), T14.2
TBLL: M13.5 (Led), T9.1
TERRACE_AMBIENT_LIGHT: M25.1 (PWM), M25.2 (PWM), U1.13 (PWM_13)
TERRACE_LIGHT: M10.1 (PWM), M10.2 (PWM), U1_ESP32-DEVKITC1.11 (IO27)
TL: M10.5 (Led), T6.2
WALL_BOUNCE_LIGHT: M8.1 (PWM), M8.2 (PWM), U1_ESP32-DEVKITC1.15 (IO13)
WASHROOM_LIGHT: M9.1 (PWM), M9.2 (PWM), U1_ESP32-DEVKITC1.8 (IO33)
WBL: M7.5 (Led), T5.1
WL: M9.5 (Led), T6.1
ZMCT103C_CURRENT: J12_ZMCT103C1.2, U1_ESP32-DEVKITC1.5 (IO34)
ZMPT101B_VOLTAGE: J9_ZMPT1.3, U1_ESP32-DEVKITC1.6 (IO35)

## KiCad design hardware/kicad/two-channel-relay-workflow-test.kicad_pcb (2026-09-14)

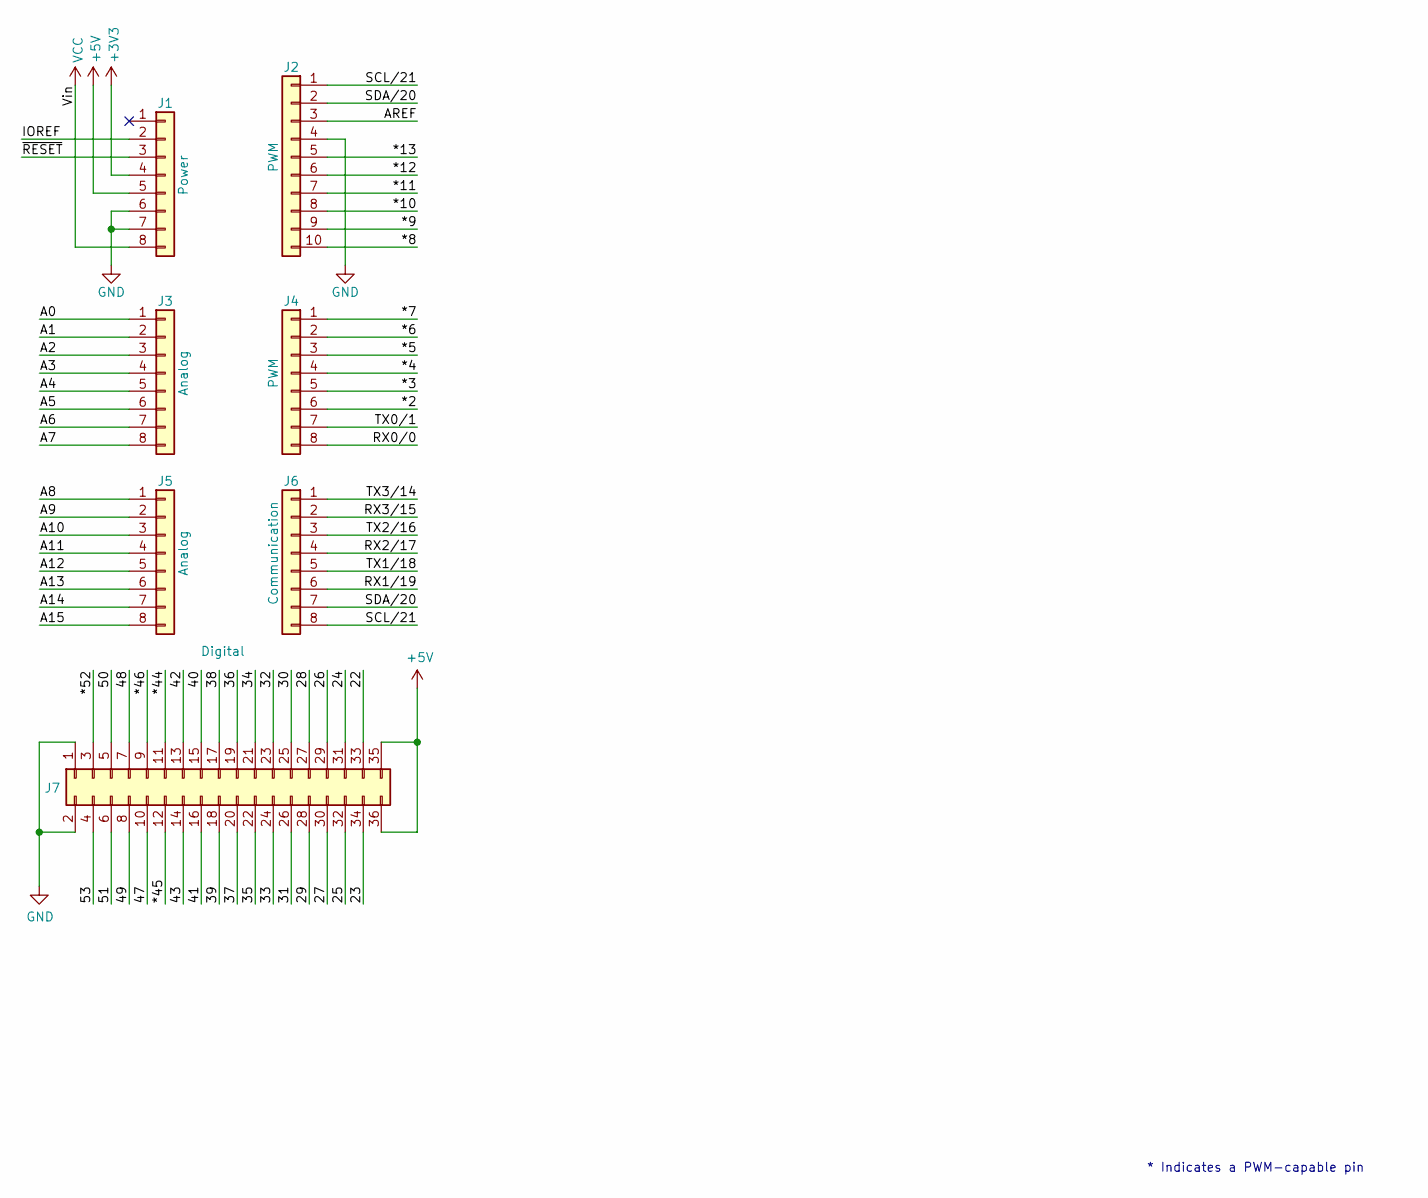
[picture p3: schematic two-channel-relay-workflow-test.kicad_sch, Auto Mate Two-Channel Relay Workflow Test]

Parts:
J1: Power; PinSocket_1x08_P2.54mm_Vertical
J2: PWM; PinSocket_1x10_P2.54mm_Vertical
J3, J5: Analog; PinSocket_1x08_P2.54mm_Vertical
J4: PWM; PinSocket_1x08_P2.54mm_Vertical
J6: Communication; PinSocket_1x08_P2.54mm_Vertical
J7: Digital; PinSocket_2x18_P2.54mm_Vertical

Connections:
+3V3: J1.4
+5V: J1.5, J7.35, J7.36
/22: J7.33
/23: J7.34
/24: J7.31
/25: J7.32
/26: J7.29
/27: J7.30
/28: J7.27
/29: J7.28
/30: J7.25
/31: J7.26
/32: J7.23
/33: J7.24
/34: J7.21
/35: J7.22
/36: J7.19
/37: J7.20
/38: J7.17
/39: J7.18
/40: J7.15
/41: J7.16
/42: J7.13
/43: J7.14
/47: J7.10
/48: J7.7
/49: J7.8
/50: J7.5
/51: J7.6
/53: J7.4
/*2: J4.6
/*3: J4.5
/*4: J4.4
/*5: J4.3
/*6: J4.2
/*7: J4.1
/*8: J2.10
/*9: J2.9
/*10: J2.8
/*11: J2.7
/*12: J2.6
/*13: J2.5
/*44: J7.11
/*45: J7.12
/*46: J7.9
/*52: J7.3
/A0: J3.1
/A1: J3.2
/A2: J3.3
/A3: J3.4
/A4: J3.5
/A5: J3.6
/A6: J3.7
/A7: J3.8
/A8: J5.1
/A9: J5.2
/A10: J5.3
/A11: J5.4
/A12: J5.5
/A13: J5.6
/A14: J5.7
/A15: J5.8
/AREF: J2.3
/IOREF: J1.2
/RX0/0: J4.8
/RX1/19: J6.6
/RX2/17: J6.4
/RX3/15: J6.2
/SCL/21: J2.1, J6.8
/SDA/20: J2.2, J6.7
/TX0/1: J4.7
/TX1/18: J6.5
/TX2/16: J6.3
/TX3/14: J6.1
/~RESET: J1.3
GND: J1.6, J1.7, J2.4, J7.1, J7.2
VCC: J1.8

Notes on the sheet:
* Indicates a PWM-capable pin

Board: 2 copper layers, 13 parts (0 on the bottom side), 4 nets, no tracks yet.

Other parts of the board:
MH1, MH2, MH3, MH4, MH5, MH6: MountingHole_3.2mm

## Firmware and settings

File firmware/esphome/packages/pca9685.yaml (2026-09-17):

# PCA9685 Configuration for AutoMate
# Single 16-channel PWM expander @ I2C address 0x40.
# CH0-CH13 assigned (14 channels). CH14=BACKUP_01, CH15=BACKUP_02 kept as
# NAMED backup channels so future devices can be mapped without restructuring.
# OE is strapped LOW in the module (outputs always enabled): no ESP32 OE gate,
# no pull-up, and no GPIO is allocated for OE.

i2c:
  - id: bus_a
    sda: GPIO21
    scl: GPIO22
    frequency: 50kHz

pca9685:
  - id: pca9685_hub
    i2c_id: bus_a
    address: 0x40
    frequency: 1000Hz

output:
  # --- Active channels (CH0-CH13) ---
  - platform: pca9685
    id: output_monitor1_backlight
    pca9685_id: pca9685_hub
    channel: 0
  - platform: pca9685
    id: output_desk_light1
    pca9685_id: pca9685_hub
    channel: 1
  - platform: pca9685
    id: output_table_light
    pca9685_id: pca9685_hub
    channel: 2
  - platform: pca9685
    id: output_shelf_light1
    pca9685_id: pca9685_hub
    channel: 3
  - platform: pca9685
    id: output_monitor2_backlight
    pca9685_id: pca9685_hub
    channel: 4
  - platform: pca9685
    id: output_desk_light2
    pca9685_id: pca9685_hub
    channel: 5
  - platform: pca9685
    id: output_shelf_light2
    pca9685_id: pca9685_hub
    channel: 6
  - platform: pca9685
    id: output_cupboard_bounce_light
    pca9685_id: pca9685_hub
    channel: 7
  - platform: pca9685
    id: output_cupboard_spot_light
    pca9685_id: pca9685_hub
    channel: 8
  - platform: pca9685
    id: output_door_spot_light
    pca9685_id: pca9685_hub
    channel: 9
  - platform: pca9685
    id: output_monitor3_backlight
    pca9685_id: pca9685_hub
    channel: 10
  - platform: pca9685
    id: output_monitor4_backlight
    pca9685_id: pca9685_hub
    channel: 11
  - platform: pca9685
    id: output_exhaust_fans
    pca9685_id: pca9685_hub
    channel: 12
  - platform: pca9685
    id: output_terrace_ambient_light
    pca9685_id: pca9685_hub
    channel: 13

  # --- Backup channels (CH14-CH15) - named, reserved for future devices ---
  - platform: pca9685
    id: output_backup_01
    pca9685_id: pca9685_hub
    channel: 14
  - platform: pca9685
    id: output_backup_02
    pca9685_id: pca9685_hub
    channel: 15

light:
  - platform: monochromatic
    id: light_monitor1_backlight
    name: "Monitor1 Backlight"
    restore_mode: RESTORE_DEFAULT_OFF
    output: output_monitor1_backlight
    on_turn_on:
      then:
        - script.execute: increment_12v_users
        - script.execute: blink_led
    on_turn_off:
      then:
        - script.execute: decrement_12v_users
        - script.execute: blink_led
    on_state:
      then:
        - lambda: |-
            auto state = id(light_monitor1_backlight).current_values;
            id(monitor1_backlight_prev_state) = state.is_on();
            id(monitor1_backlight_prev_brightness) = state.get_brightness();
            ESP_LOGD("light", "Monitor1 Backlight state saved: On - %s, Brightness - %.0f%%", id(monitor1_backlight_prev_state) ? "Yes" : "No", id(monitor1_backlight_prev_brightness) * 100);
  - platform: monochromatic
    id: light_desk_light1
    name: "Desk Light1"
    restore_mode: RESTORE_DEFAULT_OFF
    output: output_desk_light1
    on_turn_on:
      then:
        - script.execute: increment_12v_users
        - script.execute: blink_led
    on_turn_off:
      then:
        - script.execute: decrement_12v_users
        - script.execute: blink_led
    on_state:
      then:
        - lambda: |-
            auto state = id(light_desk_light1).current_values;
            id(desk_light1_prev_state) = state.is_on();
            id(desk_light1_prev_brightness) = state.get_brightness();
            ESP_LOGD("light", "Desk Light1 state saved: On - %s, Brightness - %.0f%%", id(desk_light1_prev_state) ? "Yes" : "No", id(desk_light1_prev_brightness) * 100);
  - platform: monochromatic
    id: light_table_light
    name: "Table Light"
    restore_mode: RESTORE_DEFAULT_OFF
    output: output_table_light
    on_turn_on:
      then:
        - script.execute: increment_12v_users
        - script.execute: blink_led
    on_turn_off:
      then:
        - script.execute: decrement_12v_users
        - script.execute: blink_led
    on_state:
      then:
        - lambda: |-
            auto state = id(light_table_light).current_values;
            id(table_light_prev_state) = state.is_on();
            id(table_light_prev_brightness) = state.get_brightness();
            ESP_LOGD("light", "Table Light state saved: On - %s, Brightness - %.0f%%", id(table_light_prev_state) ? "Yes" : "No", id(table_light_prev_brightness) * 100);
  - platform: monochromatic
    id: light_shelf_light1
    name: "Shelf Light1"
    restore_mode: RESTORE_DEFAULT_OFF
    output: output_shelf_light1
    on_turn_on:
      then:
        - script.execute: increment_12v_users
        - script.execute: blink_led
    on_turn_off:
      then:
        - script.execute: decrement_12v_users
        - script.execute: blink_led
    on_state:
      then:
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

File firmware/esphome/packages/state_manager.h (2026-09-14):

#pragma once

#include "esphome/core/component.h"
#include "esphome/core/preferences.h"
#include <vector>
#include <cstdint>
#include <cstring>

namespace esphome {
namespace automate {

enum RelayId : uint8_t {
  RELAY_FAN = 0,
  RELAY_CEILING = 1,
  RELAY_12V = 2,
  RELAY_STABILIZER = 3,
  RELAY_DESK1 = 4,
  RELAY_DESK2 = 5,
  RELAY_DESK3 = 6,
  RELAY_AC = 7,
  RELAY_30A = 8,
  RELAY_COUNT = 9
};

enum PwmId : uint8_t {
  PWM_CEILING_WARM = 0,
  PWM_CEILING_COLD = 1,
  PWM_DESK1_WARM = 2,
  PWM_DESK1_COLD = 3,
  PWM_DESK2_WARM = 4,
  PWM_DESK2_COLD = 5,
  PWM_MONITOR1_BACKLIGHT = 6,
  PWM_DESK_LIGHT1 = 7,
  PWM_TABLE_LIGHT = 8,
  PWM_SHELF_LIGHT1 = 9,
  PWM_MONITOR2_BACKLIGHT = 10,
  PWM_DESK_LIGHT2 = 11,
  PWM_SHELF_LIGHT2 = 12,
  PWM_WALL_BOUNCE = 13,
  PWM_PHOTO_SPOT = 14,
  PWM_CUPBOARD_BOUNCE = 15,
  PWM_CUPBOARD_SPOT = 16,
  PWM_DOOR_SPOT = 17,
  PWM_MONITOR_LIGHT3 = 18,
  PWM_MONITOR_LIGHT4 = 19,
  PWM_EXHAUST_FANS = 20,
  PWM_WASHROOM_LIGHT = 21,
  PWM_TERRACE_LIGHT = 22,
  PWM_TERRACE_AMBIENT = 23,
  PWM_COUNT = 24
};

enum MaintenanceMode : uint8_t {
  MAINTENANCE_AUTO = 0,
  MAINTENANCE_FORCE_ON = 1,
  MAINTENANCE_FORCE_OFF = 2
};

constexpr size_t MAX_SCENES = 10;
constexpr size_t SCENE_NAME_MAX_LEN = 32;
constexpr uint32_t SCENE_STORAGE_VERSION = 1;
constexpr uint32_t STATE_STORAGE_VERSION = 1;

struct SceneData {
  uint32_t version;
  uint32_t crc32;
  char name[SCENE_NAME_MAX_LEN];
  float pwm_values[PWM_COUNT];
  bool relay_values[RELAY_COUNT];
  uint32_t timestamp;
};

struct DesiredState {
  uint32_t version;
  uint32_t crc32;
  float pwm_values[PWM_COUNT];
  bool relay_values[RELAY_COUNT];
  MaintenanceMode maint_modes[RELAY_COUNT];
  uint32_t timestamp;
};

class StateManager : public Component, public PreferenceObject {
 public:
  StateManager() = default;

  void setup() override;
  void dump_config() override;

  void set_desired_pwm(PwmId id, float value);
  void set_desired_relay(RelayId id, bool value);
  float get_desired_pwm(PwmId id) const;
  bool get_desired_relay(RelayId id) const;
  MaintenanceMode get_maintenance_mode(RelayId id) const;
  void set_maintenance_mode(RelayId id, MaintenanceMode mode);

  bool check_interlocks(RelayId id, bool value);
  void update_dependency_relays();

  void save_scene(uint8_t scene_id, const char* name);
  bool load_scene(uint8_t scene_id);
  void delete_scene(uint8_t scene_id);

  bool restore_valid_state();
  bool validate_state_safety();
  void set_all_outputs_off();
  void update_effective_outputs();

  void save_desired_state();
  bool load_desired_state();
  void load_scenes();

  uint32_t calculate_crc32(const void* data, size_t length);

  void restore_valid_state_service();
  void save_scene_service(uint8_t scene_id, const std::string& name);
  void load_scene_service(uint8_t scene_id);
  void delete_scene_service(uint8_t scene_id);

  std::string get_state_summary();

 private:
  DesiredState desired_state_;
  MaintenanceMode maint_modes_[RELAY_COUNT];
  bool initialized_ = false;
};

}  // namespace automate
}  // namespace esphome

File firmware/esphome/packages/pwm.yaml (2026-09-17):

# PWM Configuration for AutoMate (Approved Transport)
# 10 LEDC outputs from ESP32: 6 CCT (high-speed CH0-5) + 4 single-channel.
# All at 10 kHz for smooth dimming and no camera flicker.
#
# GPIO Assignment (10 ESP32 LEDC channels):
#   GPIO18 -> Ceiling Warm      (LEDC CH0)
#   GPIO19 -> Ceiling Cold      (LEDC CH1)
#   GPIO25 -> Desk 1 Warm       (LEDC CH2)
#   GPIO26 -> Desk 1 Cold       (LEDC CH3)
#   GPIO4  -> Desk 2 Warm       (LEDC CH4)  [strapping - no external pull]
#   GPIO5  -> Desk 2 Cold       (LEDC CH5)  [strapping - no external pull]
#   GPIO12 -> Photo Spot Light  (LEDC CH6)
#   GPIO13 -> Wall Bounce Light (LEDC CH7)
#   GPIO27 -> Terrace Light     (LEDC CH8)
#   GPIO33 -> Washroom Light    (LEDC CH9)
#
# Reserved / not for PWM:
#   GPIO1/3 = UART0; GPIO6-11,16,17 = flash; GPIO28-31 not exposed;
#   GPIO34-39 input-only; GPIO21/22 = I2C; GPIO0 = PCA9685 OE;
#   GPIO20/23/24 = 74HC595; GPIO2 = on-board LED; GPIO32 = 30A relay.
# All remaining single-channel outputs route through PCA9685 (packages/pca9685.yaml).

# Global variables for light state persistence (restored on boot)
globals:
  - id: ceiling_prev_state
    type: bool
    restore_value: yes
    initial_value: 'false'
  - id: ceiling_prev_brightness
    type: float
    restore_value: yes
    initial_value: '1.0'
  - id: ceiling_prev_color_temp
    type: float
    restore_value: yes
    initial_value: '370'
  - id: desk1_prev_state
    type: bool
    restore_value: yes
    initial_value: 'false'
  - id: desk1_prev_brightness
    type: float
    restore_value: yes
    initial_value: '1.0'
  - id: desk1_prev_color_temp
    type: float
    restore_value: yes
    initial_value: '370'
  - id: desk2_prev_state
    type: bool
    restore_value: yes
    initial_value: 'false'
  - id: desk2_prev_brightness
    type: float
    restore_value: yes
    initial_value: '1.0'
  - id: desk2_prev_color_temp
    type: float
    restore_value: yes
    initial_value: '370'
  - id: photo_spot_prev_state
    type: bool
    restore_value: yes
    initial_value: 'false'
  - id: photo_spot_prev_brightness
    type: float
    restore_value: yes
    initial_value: '1.0'
  - id: wall_bounce_prev_state
    type: bool
    restore_value: yes
    initial_value: 'false'
  - id: wall_bounce_prev_brightness
    type: float
    restore_value: yes
    initial_value: '1.0'
  - id: terrace_prev_state
    type: bool
    restore_value: yes
    initial_value: 'false'
  - id: terrace_prev_brightness
    type: float
    restore_value: yes
    initial_value: '1.0'
  - id: washroom_prev_state
    type: bool
    restore_value: yes
    initial_value: 'false'
  - id: washroom_prev_brightness
    type: float
    restore_value: yes
    initial_value: '1.0'
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

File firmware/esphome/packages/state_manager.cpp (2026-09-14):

#include "state_manager.h"
#include "esphome/core/log.h"
#include <time.h>

namespace esphome {
namespace automate {

static const char* const TAG = "state_mgr";

void StateManager::setup() {
  this->load_desired_state();
  for (uint8_t i = 0; i < RELAY_COUNT; i++) {
    maint_modes_[i] = MAINTENANCE_AUTO;
  }
  this->load_scenes();
  initialized_ = true;
  ESP_LOGI(TAG, "State manager initialized");
}

void StateManager::dump_config() {
  ESP_LOGCONFIG(TAG, "AutoMate State Manager");
}

void StateManager::set_desired_pwm(PwmId id, float value) {
  if (id >= PWM_COUNT) return;
  value = std::max(0.0f, std::min(1.0f, value));
  desired_state_.pwm_values[id] = value;
  this->save_desired_state();
  this->update_effective_outputs();
}

void StateManager::set_desired_relay(RelayId id, bool value) {
  if (id >= RELAY_COUNT) return;
  if (maint_modes_[id] == MAINTENANCE_FORCE_OFF && value) {
    ESP_LOGW(TAG, "Relay %d blocked by FORCE_OFF", id);
    return;
  }
  if (maint_modes_[id] == MAINTENANCE_FORCE_ON && !value) {
    ESP_LOGW(TAG, "Relay %d blocked by FORCE_ON", id);
    return;
  }
  if (id == RELAY_CEILING || id == RELAY_12V || id == RELAY_STABILIZER) {
    if (!this->check_interlocks(id, value)) {
      ESP_LOGW(TAG, "Relay %d blocked by interlock", id);
      return;
    }
  }
  desired_state_.relay_values[id] = value;
  this->save_desired_state();
  this->update_effective_outputs();
}

float StateManager::get_desired_pwm(PwmId id) const {
  if (id >= PWM_COUNT) return 0.0f;
  return desired_state_.pwm_values[id];
}

bool StateManager::get_desired_relay(RelayId id) const {
  if (id >= RELAY_COUNT) return false;
  return desired_state_.relay_values[id];
}

MaintenanceMode StateManager::get_maintenance_mode(RelayId id) const {
  if (id >= RELAY_COUNT) return MAINTENANCE_AUTO;
  return maint_modes_[id];
}

void StateManager::set_maintenance_mode(RelayId id, MaintenanceMode mode) {
  if (id >= RELAY_COUNT) return;
  if (mode == MAINTENANCE_FORCE_OFF) {
    desired_state_.relay_values[id] = false;
    this->update_effective_outputs();
  }
  maint_modes_[id] = mode;
  desired_state_.maint_modes[id] = mode;
  this->save_desired_state();
  ESP_LOGI(TAG, "Relay %d maintenance mode: %d", id, mode);
}

bool StateManager::check_interlocks(RelayId id, bool value) {
  if (!value) return true;
  switch (id) {
    case RELAY_CEILING:
      return (desired_state_.pwm_values[PWM_CEILING_WARM] > 0.01f || 
              desired_state_.pwm_values[PWM_CEILING_COLD] > 0.01f);
    case RELAY_12V:
      for (uint8_t i = PWM_DESK1_WARM; i < PWM_COUNT; i++) {
        if (desired_state_.pwm_values[i] > 0.01f) return true;
      }
      return false;
    case RELAY_STABILIZER:
      return (desired_state_.relay_values[RELAY_DESK1] ||
              desired_state_.relay_values[RELAY_DESK2] ||
              desired_state_.relay_values[RELAY_DESK3]);
    default:
      return true;
  }
}

void StateManager::update_dependency_relays() {
  bool ceiling_on = (desired_state_.pwm_values[PWM_CEILING_WARM] > 0.01f || 
                     desired_state_.pwm_values[PWM_CEILING_COLD] > 0.01f);
  if (maint_modes_[RELAY_CEILING] == MAINTENANCE_AUTO) {
    desired_state_.relay_values[RELAY_CEILING] = ceiling_on;
  }
  bool any_non_ceiling_pwm = false;
  for (uint8_t i = PWM_DESK1_WARM; i < PWM_COUNT; i++) {
    if (desired_state_.pwm_values[i] > 0.01f) {
      any_non_ceiling_pwm = true;
      break;
    }
  }
  if (maint_modes_[RELAY_12V] == MAINTENANCE_AUTO) {
    desired_state_.relay_values[RELAY_12V] = any_non_ceiling_pwm;
  }
  bool any_desk_on = (desired_state_.relay_values[RELAY_DESK1] ||
                      desired_state_.relay_values[RELAY_DESK2] ||
                      desired_state_.relay_values[RELAY_DESK3]);
  if (maint_modes_[RELAY_STABILIZER] == MAINTENANCE_AUTO) {
    desired_state_.relay_values[RELAY_STABILIZER] = any_desk_on;
  }
  this->save_desired_state();
  this->update_effective_outputs();
}
void StateManager::save_scene(uint8_t scene_id, const char* name) {
  if (scene_id >= MAX_SCENES) return;
  SceneData scene;
  scene.version = SCENE_STORAGE_VERSION;
  strncpy(scene.name, name, SCENE_NAME_MAX_LEN - 1);
  scene.name[SCENE_NAME_MAX_LEN - 1] = '\0';
  memcpy(scene.pwm_values, desired_state_.pwm_values, sizeof(desired_state_.pwm_values));
  memcpy(scene.relay_values, desired_state_.relay_values, sizeof(desired_state_.relay_values));
  scene.timestamp = (uint32_t) time(nullptr);
  scene.crc32 = this->calculate_crc32(&scene, sizeof(SceneData) - sizeof(uint32_t));
  char key[16];
  snprintf(key, sizeof(key), "scene_%d", scene_id);
  this->prefs_put(key, &scene, sizeof(SceneData));
  ESP_LOGI(TAG, "Saved scene %d: %s", scene_id, name);
}

bool StateManager::load_scene(uint8_t scene_id) {
  if (scene_id >= MAX_SCENES) return false;
  char key[16];
  snprintf(key, sizeof(key), "scene_%d", scene_id);
  SceneData scene;
  size_t len = this->prefs_get(key, &scene, sizeof(SceneData));
  if (len != sizeof(SceneData)) {
    ESP_LOGW(TAG, "Scene %d not found or corrupt", scene_id);
    return false;
  }
  uint32_t crc = this->calculate_crc32(&scene, sizeof(SceneData) - sizeof(uint32_t));
  if (crc != scene.crc32) {
    ESP_LOGE(TAG, "Scene %d CRC mismatch - corrupt!", scene_id);
    return false;
  }
  if (scene.version != SCENE_STORAGE_VERSION) {
    ESP_LOGW(TAG, "Scene %d version mismatch", scene_id);
    return false;
  }
  for (uint8_t i = 0; i < PWM_COUNT; i++) {
    this->set_desired_pwm(static_cast<PwmId>(i), scene.pwm_values[i]);
  }
  for (uint8_t i = 0; i < RELAY_COUNT; i++) {
    this->set_desired_relay(static_cast<RelayId>(i), scene.relay_values[i]);
  }
  ESP_LOGI(TAG, "Loaded scene %d: %s", scene_id, scene.name);
  return true;
}

void StateManager::delete_scene(uint8_t scene_id) {
  if (scene_id >= MAX_SCENES) return;
  char key[16];
  snprintf(key, sizeof(key), "scene_%d", scene_id);
  this->prefs_remove(key);
  ESP_LOGI(TAG, "Deleted scene %d", scene_id);
}
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

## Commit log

2026-09-11 docs: record validated KiCad MCP workflow
2026-09-14 firmware: compilable ESPHome assembly + docs aligned to approved PWM transport
    Compose configuration.yaml from modular packages; esphome config + full compile pass. PWM: 10 ESP32 LEDC (6 CCT cwww + 4 single) + 14 PCA9685 + BACKUP_01/02. Relays via native sn74hc595 (GPIO20/23/15) + 30A direct. restore_mode RESTORE_DEFAULT_OFF on 23 lights + 9 relays. Fixed ESPHome platform renames (on_boot, aht10, bmp280_i2c, adc, cwww, nec). ESPHome-hardware GPIO moves: RCLK->GPIO15, door->GPIO14. state_machine excluded (custom_component removed). Updated pin-budget, PCB_DESIGN_GUIDE, schematic-build, architecture/traceability/gates/ai-context, release-evidence.
    [state_machine.yaml]
2026-09-14 fix(hw): move 74HC595 SER from GPIO20 to GPIO0 for ESP32-WROOM DevKit
    GPIO20 is not broken out on the ESP32-WROOM DevKit header. Reassign SER (shift-register serial data) to GPIO0, freed after removing the PCA9685 OE gate. GPIO0 is the BOOT/strapping pin (no external pull). Docs: pin-budget, PCB_DESIGN_GUIDE, schematic-build, release-evidence. Recompiled + re-flashed.
2026-09-14 firmware: add health monitoring (temp, uptime, wifi, version) + activity LED fixes + DHCP
    [pca9685.yaml, pwm.yaml]
2026-09-14 hardware: add KiCad project files (schematics, PCBs, pro) for AutoMate_Rebuild and AutoMate_Custom_PCB
    [AutoMate.kicad_pcb, AutoMate.kicad_sch, AutoMate_Rebuild.kicad_pcb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]
2026-09-16 v1.0.3: Fix 12V driver automation and state persistence
    [AutoMate.kicad_pcb, AutoMate.kicad_sch]
2026-09-17 deploy: v1.0.5 - Fixed 12V driver restart race condition, added restart API service
    - Fixed 12V driver race condition on boot: now restores lights first, then sets 12V driver based on actual light states
    - Removed invalid 'await 500ms' and 'light_desk3' references from on_boot lambda
    - Fixed light state checks to use .current_values.is_on() API
    - Added restart API service accessible via Home Assistant
    - Uses esp_restart() for clean restart that preserves state
    - All globals have restore_value: yes for state persistence
    [AutoMate.kicad_sch]
2026-09-17 deploy: v1.0.6 - Fixed state restoration race condition on boot
    - Added boot_complete global flag to prevent binary sensor automations from running during boot
    - Rewrote on_boot lambda to restore lights first, then relays atomically
    - Updated non_ceiling_pwm_active, ceiling_pwm_active, desks_active binary sensors to check boot_complete before controlling relays
    - This prevents the race condition where binary sensor on_state handlers would turn off relays after they were restored
    [AutoMate.kicad_sch]
2026-09-17 deploy: v1.0.7 - Complete relay logic rewrite for reliable state restoration
    - All relay globals now have restore_value: yes for persistence across restarts
    - Removed binary sensor automations (non_ceiling_pwm_active, ceiling_pwm_active, desks_active) that caused race conditions
    - New counter-based 12V driver management (increment_12v_users/decrement_12v_users scripts)
    - Ceiling driver controlled directly by ceiling light on_turn_on/off
    - Voltage stabilizer controlled by desk switches (to be connected)
    - Clean boot restoration in core.yaml with boot_complete flag
    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
2026-09-17 deploy: v1.0.8 - Fixed 12V driver counter for ALL non-ceiling lights
    - Fixed relays.yaml: removed duplicate globals block and duplicate desk1/desk2 globals
    - Fixed pwm.yaml: ALL non-ceiling lights now use increment_12v_users/decrement_12v_users counter scripts
    - This ensures 12V driver turns ON when ANY non-ceiling light turns ON, and OFF only when ALL are OFF
    [pwm.yaml]
2026-09-17 deploy: v1.0.9 - Fixed desk relay/desk light global ID conflict
    - Desk lights and desk relays were using SAME global IDs (desk1_prev_state, desk2_prev_state, desk3_prev_state)
    - This caused light state restoration to overwrite relay saved state
    - Created separate globals: desk1_relay_prev_state, desk2_relay_prev_state, desk3_relay_prev_state for relays
    - Updated core.yaml on_boot to use new relay globals
    - Desk lights and desk relays are now completely independent
2026-09-17 deploy: v1.0.10 - Fixed all relay state restoration issues
    1. 12V Driver: Changed ALL relays to RESTORE_DEFAULT_OFF, added counter scripts for all non-ceiling lights
    2. Desks & Voltage Stabilizer: Added desks_active_count counter + increment/decrement scripts, connected to desk switch actions
    3. Boot Restoration: Rewrote on_boot to restore lights first (triggering counters), then relays from saved globals, then set boot_complete=true
    4. Fixed global ID conflicts: desk relays use desk1_relay_prev_state, desk lights use desk1_prev_state
    5. All relay globals now have restore_value: yes for persistence
2026-09-17 deploy: v1.0.11 - Fixed 12V driver flickering on boot
    - Added 500ms delay before relay restoration to let lights fully update states
    - Changed 12V driver boot logic to use counter (lights_using_12v_count) instead of checking light.current_values.is_on()
    - Counter is updated synchronously in on_turn_on callbacks, so it's always accurate
    - This eliminates the off-on-off-on flickering during boot
2026-09-17 deploy: v1.0.12 - Fixed 12V driver final boot sync
    - 12V driver relay is already in correct state after light restoration
    - Relay restoration now ONLY syncs template switch state (publish_state)
    - Does NOT call turn_on/turn_off on relay_12v_driver
    - Eliminates the extra ON-OFF-ON cycle during boot
2026-09-17 deploy: v1.0.13 - Complete rewrite of relay logic for reliable state restoration
    - relays.yaml: Complete rewrite with 9 simple globals (one per relay) with restore_value: yes
    - Each relay updates its global on turn_on/off via simple lambda
    - core.yaml: Simple on_boot reads globals and sets relays - NO counters, NO race conditions
    - pwm.yaml: Lights use simple scripts (turn_on_12v_driver, turn_off_12v_driver, turn_on_stabilizer, turn_off_stabilizer)
    - No binary sensor automations, no counters, no complex boot logic
    - ESPHome's RESTORE_DEFAULT_OFF handles relay hardware state
    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
2026-09-17 deploy: v1.0.14 - Complete relay automation fix
    - 12V Driver: All non-ceiling lights (PCA9685 + GPIO LEDC) use increment_12v_users/decrement_12v_users
    - Ceiling Driver: Ceiling light controls ceiling driver directly
    - Voltage Stabilizer: Desk relays (desk1/2/3) control stabilizer via increment_desk_users/decrement_desk_users
    - All PWM lights (PCA9685 + GPIO LEDC except ceiling) control 12V driver via counter
    - Desk template switches control stabilizer via desk counter scripts
    - Clean boot restoration using globals with restore_value: yes
    [pca9685.yaml, pwm.yaml]
2026-09-17 fix: v1.0.15 - Fixed light automation mappings
    - Fixed Desk 1 & 2 Lights: Now use increment_12v_users/decrement_12v_users (12V driver) instead of ceiling driver
    - Fixed Photo Spot, Wall Bounce, Terrace, Washroom: Now use 12V driver counter
    - Ceiling Light correctly uses ceiling driver only
    - All non-ceiling PWM lights now correctly use 12V driver counter
    [pwm.yaml]
2026-09-17 fix: v1.0.16 - Fixed PCA9685 turn_off actions
    - PCA9685 lights now correctly call decrement_12v_users on turn_off
    - 12V driver counter now properly increments on turn_on and decrements on turn_off for ALL non-ceiling lights
    [pca9685.yaml]
2026-09-17 fix: v1.0.17 - Fixed desk template switches stabilizer control
    - Desk 1/2/3 template switches now call increment_desk_users/decrement_desk_users
    - Stabilizer now properly controlled by desk relay states
